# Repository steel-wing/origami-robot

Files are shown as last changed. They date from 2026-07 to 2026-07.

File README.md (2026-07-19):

# Origami Robot

This is the code behind the paper "Thickness-Invariant Origami Robots for Untethered Locomotion".

There are two primary directories here: `robotics` and `simulation`. 

## robotics

cad_model

`robotics` contains everything relating to the physical robot. It has the Platformio code used to control the physical robot constructed, with the final version of the code residing in `CMR_ORIGAMI_ROBOT_GAIT.cpp`. It has all CAD files used in the construction of the robot, as well as the custom PCBs. It contains instructions for 3D printing and assembly of parts to recreate the configuration used in the paper (see the `README.md` in the folder). It also has all materials obtained during experimentation, namely, the statistical analysis of the gaits used during testing.

## simulation

maybe

`simulation` contains everything relating to the MuJoCo simulation of the robot. It has three primary files worth inspecting.

`runner.py` is used to observe individual gait profiles, and see how they perform. It is called by `gait_finder.py` to obtain distance and rotation measurements for optimization.

`gait_finder.py` contains the optimization algorithm used to identify gaits for the robot. The `budget` and `steps` variables determine how long it will take to run, and the fidelity of the results provided.

`playground.py` is a simulator for exploring robot motion manually. It uses the number keys on the keyboard to select and control individual hinges of the robot.

See the `README.md` within `simulation` for more information about how to install MuJoCo and run the code.

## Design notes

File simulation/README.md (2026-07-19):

# Installation

1. Install [Python 3.12](https://www.python.org/ftp/python/3.12.0/)
    and make sure to add it to PATH. Then restart your IDE
2. Run these in the project folder to create a new virtual environment:

    `py -3.12 -m venv mujoco312`

    `mujoco312\Scripts\activate`

    If Powershell gives you trouble, you can run this:
    \
        `(Set-ExecutionPolicy -Scope CurrentUser -ExecutionPolicy RemoteSigned)`
3. Install the dependencies via the `requirements.txt`

    `pip install -r requirements.txt`

    (this installs the `nevergrad`, `mujoco`, and `keyboard` libraries, along with their dependencies at time of writing)

4. Run `runner.py` to play around with the model or use `gait_finder.py` to explore optimizations.

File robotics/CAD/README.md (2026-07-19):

# Overview

There are 12 cells in this robot, six male (containing motors) and six female (containing other components).
These cells are numbered following this figure:



Each cell has hinges that must be glued into place for assembly, and all six female cells have gear inserts required for motion. Hinges and hinge types vary based on location, type of cell, and whether or not the hinge borders a short edge (two of which exist on each cell) or a long edge (one of which exists on each cell). The two short edges are next to each other on one side of the cell, while the long edge sits opposite them. All hinges can reasonably be installed using cyanoacrylate glue.

## Female Cells

There are three variants of female cells in this robot: the standard female cell (`Female Cell.stl`), which is used for cells 3, 6, 8, and 12, the control module female cell (`Female Cell - Microcontroller.stl`), designed to house the microcontroller and power switch, which is used for Cell 2, and the power module female cell (`Female Cell Battery.stl`), which was designed to house batteries and buck converters, and which is used as the connection point for external power. It is used for Cell 9.

Each of the female cells uses `Female Hinge 1.stl`'s to connect to male cells bordering the short edge, and `Female Hinge 2.stl`'s to connect to male cells bordering the long edge.

In between all hinges, the female cells have an L-shaped slot that accepts a gear arm. These gear arms are used to actuate the hinge while the servo rotates.

### Electrical Components

Female Cell 2 houses the microcontroller (an ESP32 Firebeetle 2), a switch, and a battery (a 4-cell, NM 4.8V 200mAh battery).
Female Cell 9 houses batteries, buck converters, and a MOSFET for limiting power. Using electrical tape to hold different components in position is advised.
All other female cells contain PCBs for daisy-chaining power and signal data through the robot. 8-wire JST cables are used for signal transmission, and XT30 cables are used for power transmission.  

### Gear Arms

Like the gears, there are three variants of gear arms. Eight `Gear Arm Standard.stl`'s should be printed, with four being reflections of the other four. These are to be inserted in female hinges bordering short edge hinges. Four `Gear Arm Center.stl`'s should be printed and inserted in female hinges bordering long edge hinges. A final, single `Gear Arm S3170G.stl` should be inserted into the Cell 9, which is a `Female Cell Battery.stl`.

## Male Cells

There are two variants of male cells in this robot: the standard male cell (`Male Cell.stl`), which is used for cells 1, 5, 7, 10, and 11, and the modified male cell (`Male Cell - Modified (S1370G).stl`) designed to fit the Futaba SG3107 servo motor, which is used for Cell 4.

Each of the standard male cells uses one `Male Hinge 1.stl` and one `Male Hinge 2.stl` to connect to a female hinge along the short edge, and two `Male Hinge 2.stl`'s to connect to a female cell along the short edge. These hinges differ only slightly to accommodate the different geometry on different sides of the cell.

The modified male cell (Cell 4) uses modified versions of the male hinges to accommodate its altered geometry. It uses two `Male Hinge 1.stl`'s to connect to Cell 9, and two `Male Hinge 3.stl`'s and two Male Hinge 4's to connect to cells 2 and 6 (one hinge of each type connects to each of the neighboring cells.)

### Servos

Once hinges are installed, motors can be inserted. All motors are Miuzei MG90S's save for the one Futaba S3170G in Cell 4. Follow the numbered figure above for placements. The motors are all secured by a press fit, and all servo motor heads should be as close to their respective hinges as possible (as in, do not insert the servos backwards. Otherwise, the gears will be unable to mesh). Gears should not be attached to servos at this point.

## Pattern Assembly

Once all cells have had hinges glued, electrical components inserted, and the female hinges have gear arms placed, the cells can be arranged following the attached diagram. All hinges are designed to work with 3mm metal pins, which are press fit into each of the from the side. After hinges are functional, signal and power cables can be routed through cells from one component to the next. Signal wires originate at the microcontroller, with specific pins for each motor defined inside of CMR_ORIGAMI_ROBOT.cpp (line 23).

### Servo Calibration Run

Once all electronics are assembled, the buck converters should be powered with a voltage of 7.4 volts, which they will step down to the 6.0V required by the servo motors. Then the microcontroller should be powered on by its 4.8V battery, and allowed to run all motors through one run of a gait. The included `CMR_ORIGAMI_ROBOT_GAIT.cpp` will correctly position all servos at the end of the run, meaning that, so long as no hinges are actuated during assembly, gears may now be applie to the motors.

### Gear Insertion

There are three gear variants used in this model, to match the three gear arm variants. Therefore, eight `Short Edge Gear.stl`'s will be used on all short edge hinges, four `Long Edge Gear.stl`'s will be used on the four long edges, and one `S1370G Gear.stl` will be used on the centermost hinge, between Cell 4 (`Male Cell - Modified (S1370G).stl`) and Cell 9 (`Female Cell Battery.stl`).

To correctly insert all gears, it can be helpful to have a thin metal shim or spatula, and a thin pair of tweezers. It is also helpful to use a few rubber bands to hold the entire robot assembly in the closed position. Using the shim to apply a force through the gear towards the servo, slide each gear over the head of its respective servo motor, and once it gets close, press hard to ensure it slides into position. Further care should be taken to ensure that the teeth of the gear mesh with the teeth of the adjacent gear arm.

Once all gears are in position any rubber bands can be removed and the robot is ready for motion.

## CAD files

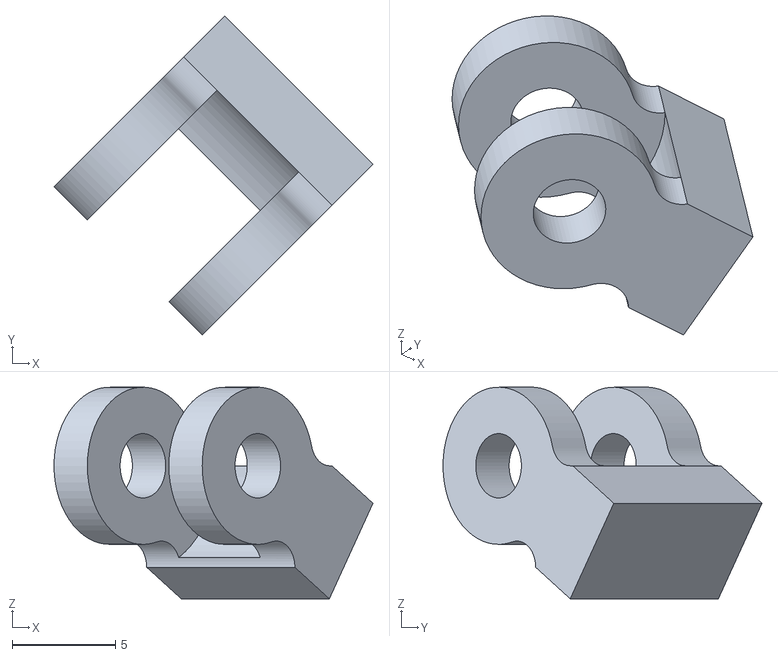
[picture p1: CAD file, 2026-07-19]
robotics/CAD/Female Cells/Female Hinge 1.stl
15.5 x 15.5 x 10.3

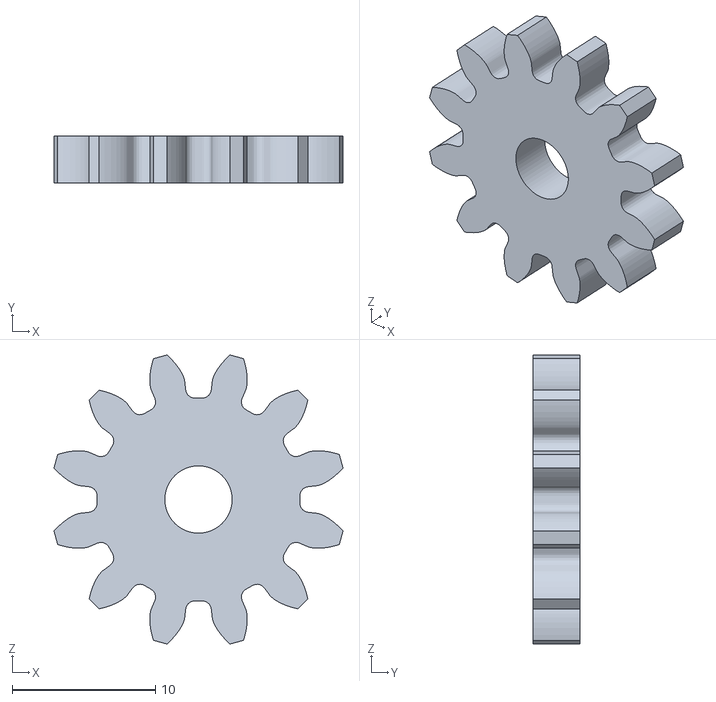
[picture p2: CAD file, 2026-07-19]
robotics/CAD/Male Cells/Long Edge Gear.stl
20.2 x 3.30 x 20.2

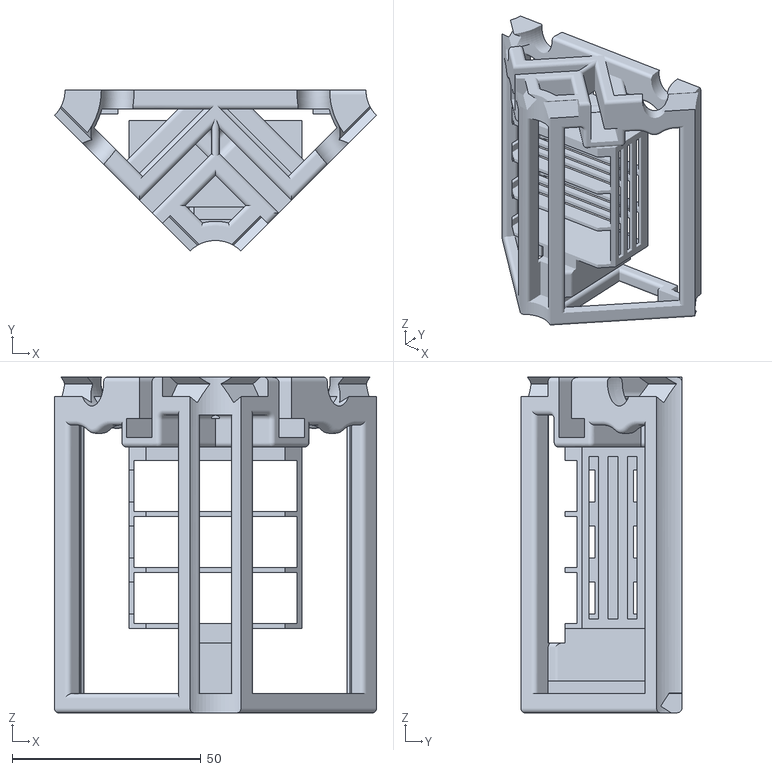
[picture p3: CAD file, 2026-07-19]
robotics/CAD/Female Cells/Female Cell - Battery.stl
85.3 x 42.7 x 88.9

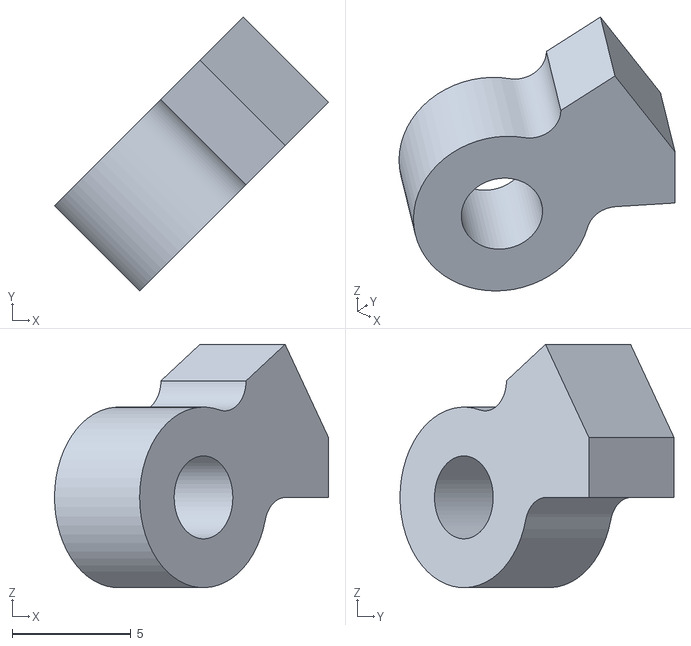
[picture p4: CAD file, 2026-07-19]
robotics/CAD/Male Cells/Male Hinge 3.stl
11.6 x 11.6 x 10.3

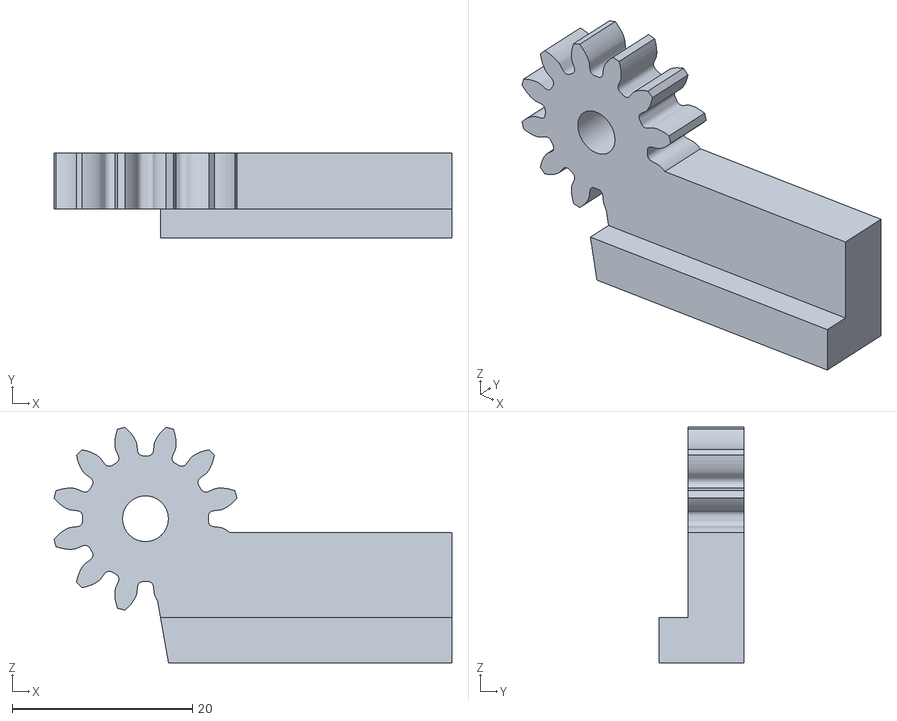
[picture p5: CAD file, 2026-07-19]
robotics/CAD/Female Cells/Long Edge Gear Arm.stl
44.2 x 9.40 x 26.2

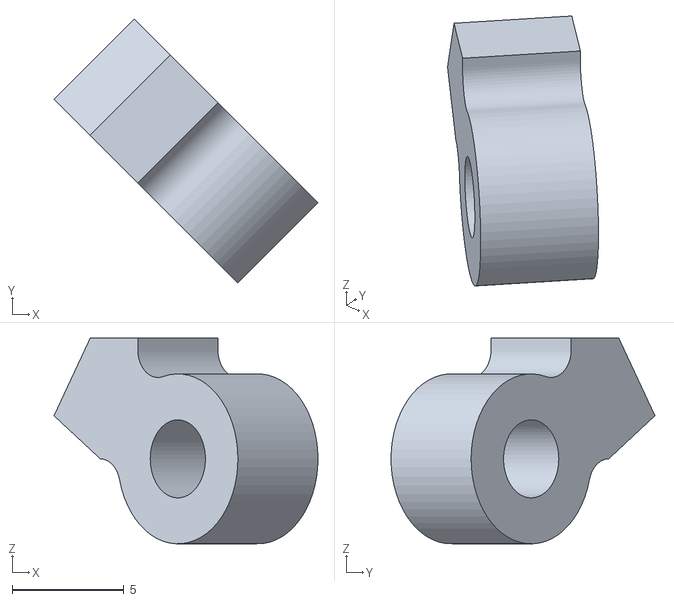
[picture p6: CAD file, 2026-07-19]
robotics/CAD/Male Cells/Male Hinge 2.stl
11.8 x 11.8 x 9.22

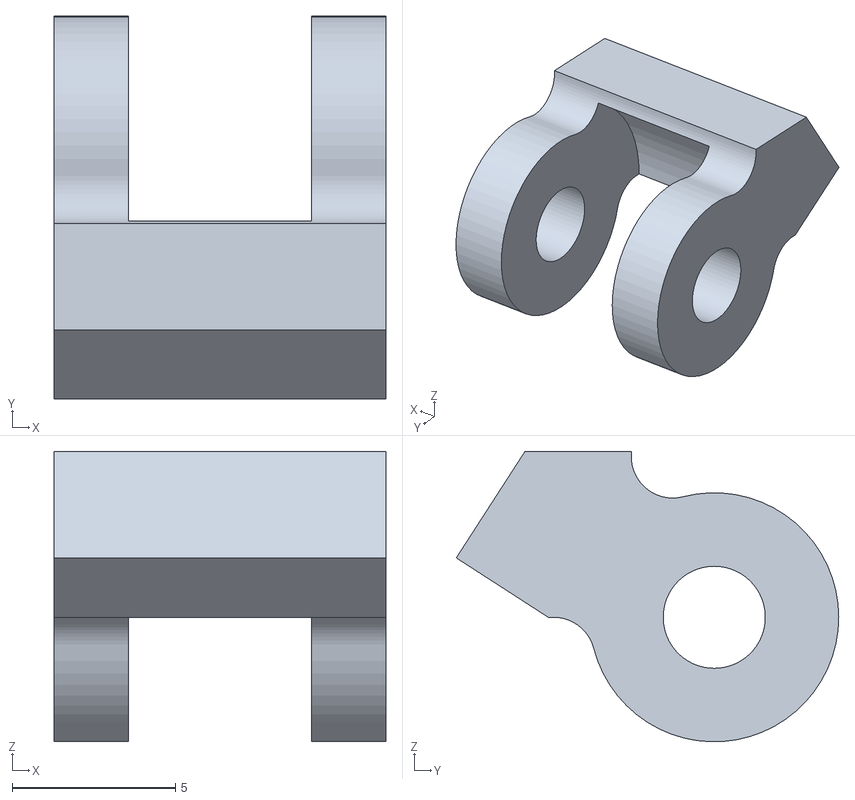
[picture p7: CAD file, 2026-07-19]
robotics/CAD/Female Cells/Female Hinge 2.stl
10.2 x 11.7 x 8.89

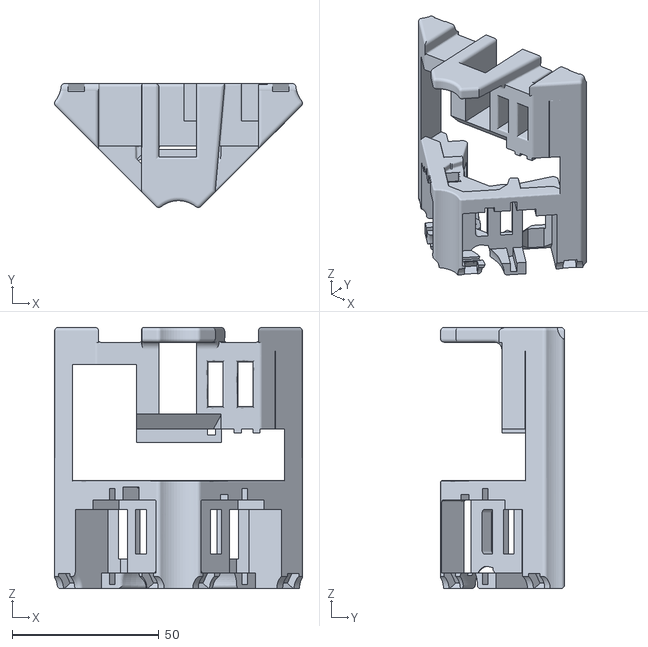
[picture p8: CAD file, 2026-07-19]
robotics/CAD/Male Cells/Male Cell.stl
84.4 x 42.2 x 88.9

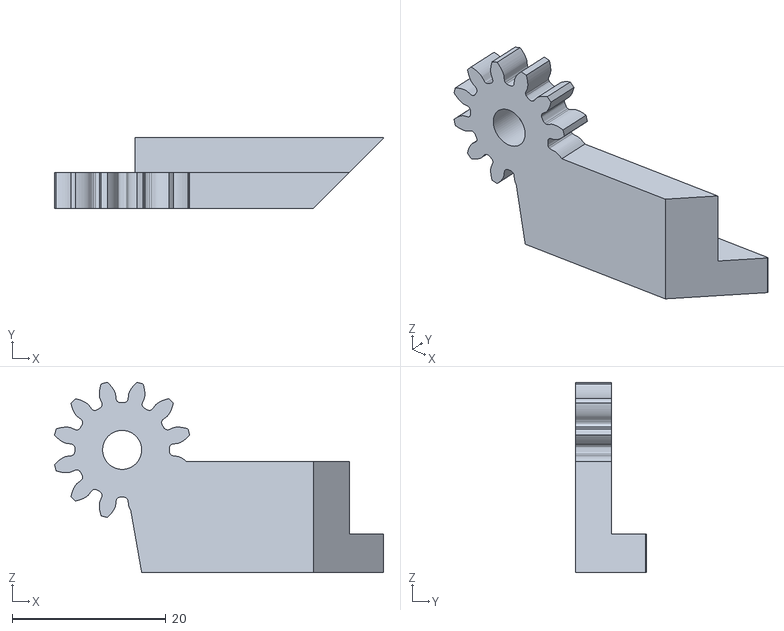
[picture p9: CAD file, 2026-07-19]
robotics/CAD/Female Cells/Short Edge Gear Arm.stl
42.9 x 9.27 x 24.8

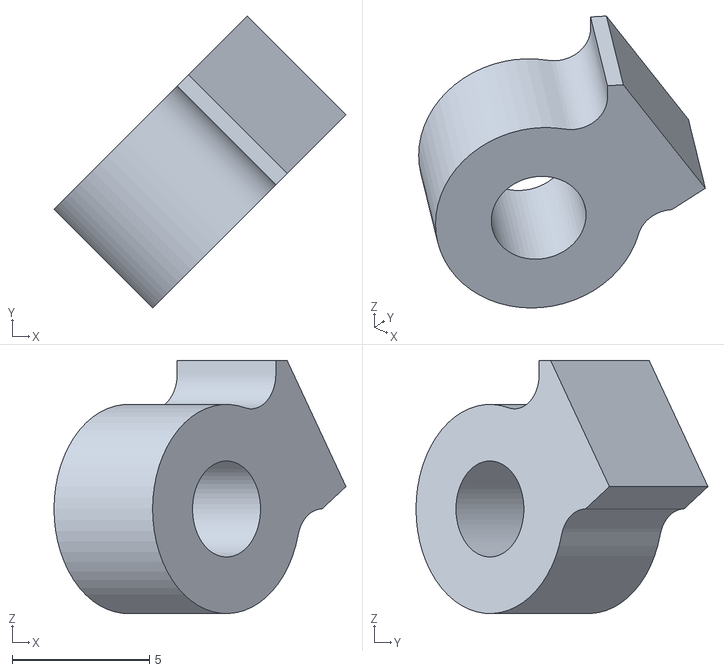
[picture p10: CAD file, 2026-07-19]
robotics/CAD/Male Cells/Male Hinge 4.stl
10.6 x 10.6 x 9.22

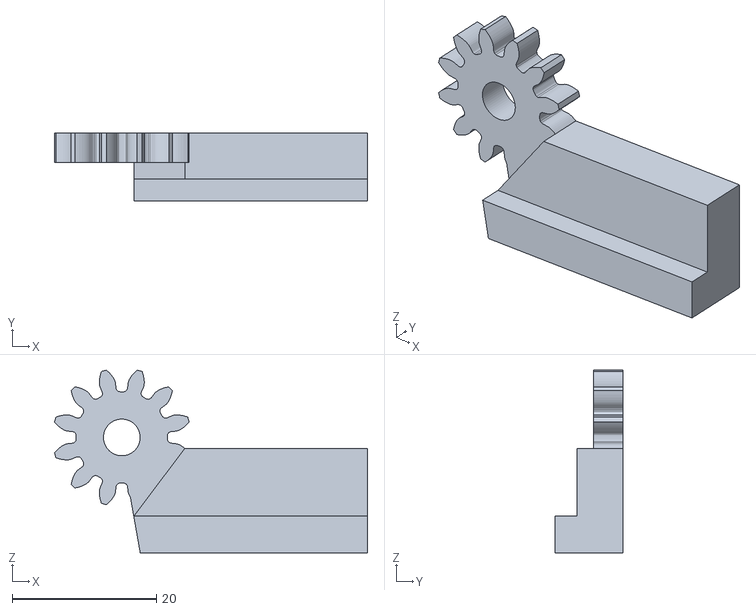
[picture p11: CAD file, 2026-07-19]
robotics/CAD/Female Cells/S3170G Gear Arm.stl
43.4 x 9.40 x 25.3

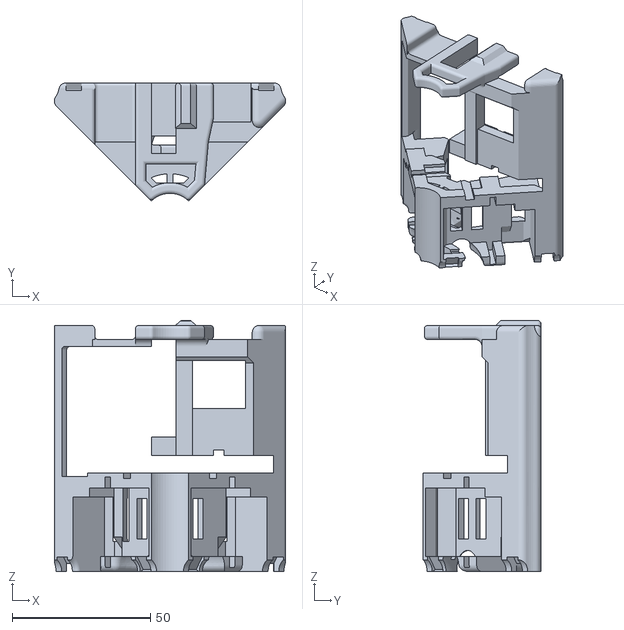
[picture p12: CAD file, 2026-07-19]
robotics/CAD/Male Cells/Male Cell - Modified (S1370G).stl
83.6 x 42.7 x 90.7

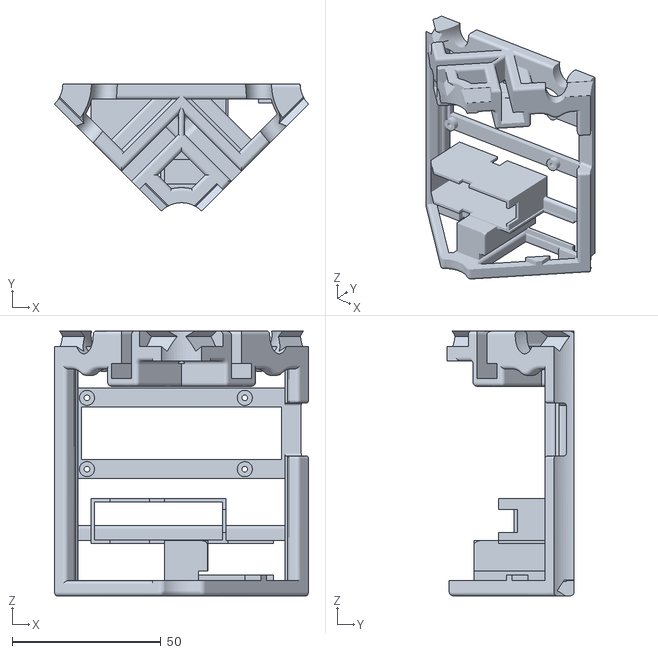
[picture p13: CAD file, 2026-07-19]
robotics/CAD/Female Cells/Female Cell - Microcontroller.stl
85.3 x 42.7 x 88.9

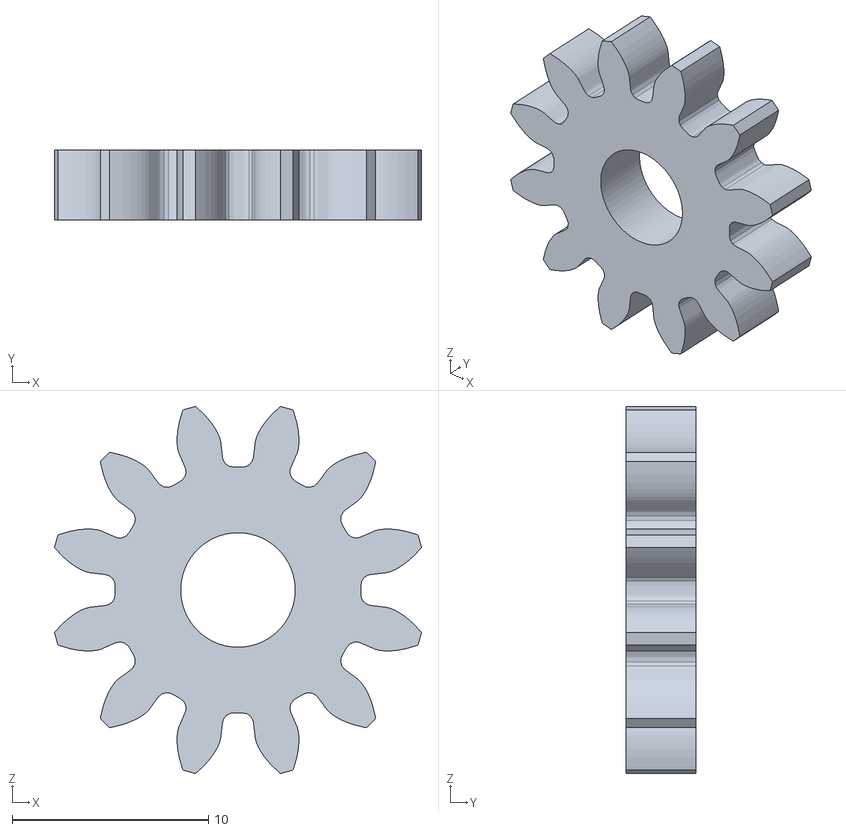
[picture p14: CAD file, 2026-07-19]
robotics/CAD/Male Cells/S1370G Gear.stl
18.7 x 3.56 x 18.7

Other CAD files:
robotics/CAD/Female Cells/Female Cell.stl
robotics/CAD/Male Cells/Male Hinge 1.stl
robotics/CAD/Male Cells/Short Edge Gear.stl

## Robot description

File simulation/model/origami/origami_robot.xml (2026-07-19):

<mujoco model="two_prisms_hinge">
    <option integrator="implicitfast" timestep="0.001"/>
    <compiler angle="radian" inertiafromgeom="true"/>
    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
    <option gravity="0 0 -9.81"/>

    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

    <worldbody>
        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
        <light pos="10 -10 20" dir="-1 1 -1.5" diffuse="0.5 0.5 0.5" directional="false" />
        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
    </worldbody>

    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
    <worldbody>
        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
        <body name="prism1_body" pos="0 0 0" euler="0 0 3.14159">
            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
            <joint type="free"/>

            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
            <body name="prism2_body" pos="0.0530 -0.0530 0" euler="0 0 3.14159">
                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
                <joint name="jaw_hinge_2" type="hinge" pos="0.02652 -0.02652 0" axis="-1 1 0" range="0 3.14" damping="0.02"/>

                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
                <body name="prism4_body" pos="0 -0.10606 0" euler="0 0 3.141592">
                    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
                    <joint name="jaw_hinge_4" type="hinge" pos="0 -0.0530 -0.09" axis="-1 0 0" range="0 3.14" damping="0.02"/>

                    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
                    <body name="prism6_body" pos="-0.0530 -0.0530 0" euler="0 0 3.141592">
                        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
                        <joint name="jaw_hinge_6" type="hinge" pos="-0.02652 -0.02652 0" axis="-1 -1 0" range="0 3.14" damping="0.02"/>
                    </body>
                </body>
            </body>

            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
            <body name="prism3_body" pos="-0.0530 -0.0530 0" euler="0 0 3.14159">
                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
                <joint name="jaw_hinge_3" type="hinge" pos="-0.02652 -0.02652 0" axis="-1 -1 0" range="0 3.14" damping="0.02"/>


                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
                <body name="prism5_body" pos="0 -0.10606 0" euler="0 0 3.141592">
                    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
                    <joint name="jaw_hinge_5" type="hinge" pos="0 -0.0530 -0.09" axis="-1 0 0" range="0 3.14" damping="0.02"/>
                </body>
            </body>

            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
            <body name="prism7_body" pos="0 -0.10606 0" euler="0 0 3.14159">
                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
                <joint name="jaw_hinge_7" type="hinge" pos="0 -0.0530 -0.09" axis="-1 0 0" range="0 3.14" damping="0.02"/>

                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
                <body name="prism8_body" pos="0.0530 -0.0530 0" euler="0 0 3.14159">
                    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
                    <joint name="jaw_hinge_8" type="hinge" pos="0.02652 -0.02652 0" axis="-1 1 0" range="0 3.14" damping="0.02"/>

                    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
                    <body name="prism10_body" pos="0 -0.10606 0" euler="0 0 3.141592">
                        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
                        <joint name="jaw_hinge_10" type="hinge" pos="0 -0.0530 -0.09" axis="-1 0 0" range="0 3.14" damping="0.02"/>

                        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
                        <body name="prism12_body" pos="-0.0530 -0.0530 0" euler="0 0 3.141592">
                            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
                            <joint name="jaw_hinge_12" type="hinge" pos="-0.02652 -0.02652 0" axis="-1 -1 0" range="0 3.14" damping="0.02"/>
                        </body>
                    </body>
                </body>

                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
                <body name="prism9_body" pos="-0.0530 -0.0530 0" euler="0 0 3.14159">
                    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
                    <joint name="jaw_hinge_9" type="hinge" pos="-0.02652 -0.02652 0" axis="-1 -1 0" range="0 3.14" damping="0.02"/>

                    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
                    <body name="prism11_body" pos="0 -0.10606 0" euler="0 0 3.141592">
                        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
                        <joint name="jaw_hinge_11" type="hinge" pos="0 -0.0530 -0.09" axis="-1 0 0" range="0 3.14" damping="0.02"/>
                    </body>
                </body>
            </body>
        </body>
    </worldbody>


    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
    <actuator>
        <position name="l_left" tendon="hinges_3_6" kp="10" kv="1" ctrlrange="0 3.14" ctrllimited="true" forcelimited="true" forcerange="-0.3924 0.3924"/>
    </actuator>

    <tendon>
        <fixed name="hinges_3_6">
            <joint joint="jaw_hinge_3" coef="0.5"/>
            <joint joint="jaw_hinge_6" coef="0.5"/>
        </fixed>
    </tendon>

    <actuator>
        <position name="r_left" joint="jaw_hinge_2" kp="10" kv="1" ctrlrange="0 3.14" ctrllimited="true" forcelimited="true" forcerange="-0.3924 0.3924"/>
    </actuator>

    <actuator>
        <position name="m_left" tendon="hinges_4_5" kp="10" kv="1" ctrlrange="0 3.14" ctrllimited="true" forcelimited="true" forcerange="-0.3924 0.3924"/>
    </actuator>

    <tendon>
        <fixed name="hinges_4_5">
            <joint joint="jaw_hinge_4" coef="0.5"/>
            <joint joint="jaw_hinge_5" coef="0.5"/>
        </fixed>
    </tendon>

    <actuator>
        <position name="center" joint="jaw_hinge_7" kp="10" kv="1" ctrlrange="0 3.14" ctrllimited="true" forcelimited="true" forcerange="-0.83385 0.83385"/>
    </actuator>

    <actuator>
        <position name="r_right" joint="jaw_hinge_8" kp="10" kv="1" ctrlrange="0 3.14" ctrllimited="true" forcelimited="true" forcerange="-0.3924 0.3924"/>
    </actuator>

    <actuator>
        <position name="l_right" tendon="hinges_9_12" kp="10" kv="1" ctrlrange="0 3.14" ctrllimited="true" forcelimited="true" forcerange="-0.3924 0.3924"/>
    </actuator>

    <tendon>
        <fixed name="hinges_9_12">
            <joint joint="jaw_hinge_9" coef="0.5"/>
            <joint joint="jaw_hinge_12" coef="0.5"/>
        </fixed>
    </tendon>

    <actuator>
        <position name="m_right" tendon="hinges_10_11" kp="10" kv="1" ctrlrange="0 3.14" ctrllimited="true" forcelimited="true" forcerange="-0.3924 0.3924"/>
    </actuator>

    <tendon>
        <fixed name="hinges_10_11">
            <joint joint="jaw_hinge_10" coef="0.5"/>
            <joint joint="jaw_hinge_11" coef="0.5"/>
        </fixed>
    </tendon>

    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
    <equality>
        <connect name="close_hex_1" body1="prism5_body" body2="prism6_body" anchor="0 0 0"/>
    </equality>

    <equality>
        <connect name="close_hex_2" body1="prism5_body" body2="prism6_body" anchor="1 -1 0"/>
    </equality>

    <equality>
        <connect name="close_hex_3" body1="prism11_body" body2="prism12_body" anchor="0 0 0"/>
    </equality>

    <equality>
        <connect name="close_hex_4" body1="prism11_body" body2="prism12_body" anchor="1 -1 0"/>
    </equality>
</mujoco>

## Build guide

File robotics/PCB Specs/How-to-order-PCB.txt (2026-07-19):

How to Order PCB

Please refer to:
https://docs.easyeda.com/en/PCB/Order-PCB

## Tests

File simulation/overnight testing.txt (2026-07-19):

        Testing mode (4, 4), with orientation 1, with y displacement loss
x 0.97
y -1.53
r 0.41
-1.53, 0.01, 0.0, 0.01, 0.0, 0.25, 2.07, 1.85, 0.16, 2.99, 1.44, 3.0, 0.2, 4, 4, 1, 1

        Testing mode (4, 4), with orientation 0, with y displacement loss
x 0.31
y 0.12
r -0.01
0.12, 1.5, 3.0, 0.34, 0.02, 0.01, 0.02, 0.01, 0.45, 1.97, 1.82, 0.04, 2.99, 4, 4, 0, 1

        Testing mode (4, 4), with orientation 1, with x displacement loss
x -1.11
y 1.59
r 0.23
-1.11, 1.38, 0.28, 0.0, 1.59, 0.26, 0.0, 2.91, 0.02, 1.87, 0.78, 3.0, 1.68, 4, 4, 1, 0

        Testing mode (4, 4), with orientation 0, with x displacement loss
x 0.13
y 0.86
r -0.31
0.13, 0.0, 0.57, 2.06, 2.37, 1.35, 0.23, 1.34, 0.0, 0.0, 1.18, 3.0, 1.09, 4, 4, 0, 0

        Testing mode (4, 4), with orientation 1, with rotation loss
x -0.13
y 1.23
r -0.04
-0.04, 0.0, 0.75, 2.4, 0.0, 3.0, 2.23, 1.85, 1.65, 0.01, 2.11, 0.2, 0.0, 4, 4, 1, 2

        Testing mode (4, 4), with orientation 0, with rotation loss
x -0.01
y -0.62
r 0.01
0.01, 0.78, 3.0, 1.7, 1.3, 0.22, 0.0, 1.74, 0.35, 0.0, 2.93, 0.01, 1.83, 4, 4, 0, 2

        Testing mode (4, 3), with orientation 1, with y displacement loss
x -0.08
y 0.31
r -0.08
0.31, 0.0, 1.08, 1.72, 1.58, 2.99, 0.86, 1.8, 0.75, 0.0, 2.18, 0.56, 2.77, 4, 3, 1, 1

        Testing mode (4, 3), with orientation 0, with y displacement loss
x 0.08
y 0.27
r -0.03
0.27, 0.0, 0.0, 0.02, 2.98, 0.0, 0.02, 0.36, 1.5, 2.94, 0.0, 0.33, 0.05, 4, 3, 0, 1

        Testing mode (4, 3), with orientation 1, with x displacement loss
x 0.26
y -0.46
r 0.74
0.26, 0.01, 0.33, 1.63, 1.86, 0.0, 2.94, 1.62, 3.0, 0.67, 0.0, 0.18, 1.32, 4, 3, 1, 0

        Testing mode (4, 3), with orientation 0, with x displacement loss
x -0.22
y -0.43
r -0.68
-0.22, 0.77, 3.0, 1.89, 0.0, 0.02, 1.03, 0.03, 0.01, 2.98, 2.99, 2.27, 0.0, 4, 3, 0, 0

        Testing mode (4, 3), with orientation 1, with rotation loss
x 0.07
y 0.72
r -0.19
-0.19, 2.94, 0.05, 1.86, 0.62, 3.0, 1.61, 1.96, 2.12, 0.27, 1.54, 0.23, 0.0, 4, 3, 1, 2

        Testing mode (4, 3), with orientation 0, with rotation loss
x 0.34
y 0.22
r -0.72
-0.72, 2.97, 0.02, 0.02, 0.02, 2.27, 2.96, 1.87, 2.99, 0.81, 1.12, 0.01, 0.0, 4, 3, 0, 2

        Testing mode (4, 1), with orientation 1, with y displacement loss
x -0.39
y -0.07
r 2.23
-0.07, 0.06, 2.71, 2.65, 2.1, 2.98, 0.69, 1.31, 0.0, 0.0, 2.99, 0.0, 0.87, 4, 1, 1, 1

        Testing mode (4, 1), with orientation 0, with y displacement loss
x -0.18
y 0.2
r 0.71
0.2, 2.09, 0.16, 2.99, 0.02, 0.96, 1.36, 0.01, 0.32, 0.0, 1.3, 2.21, 0.09, 4, 1, 0, 1

        Testing mode (4, 1), with orientation 1, with x displacement loss
x -0.31
y -0.37
r 0.18
-0.31, 0.0, 0.01, 1.15, 0.01, 0.42, 1.86, 2.19, 1.02, 0.0, 1.12, 2.99, 1.52, 4, 1, 1, 0

        Testing mode (4, 1), with orientation 0, with x displacement loss
x 0.13
y 0.24
r -1.91
0.13, 0.0, 0.19, 0.0, 0.0, 1.34, 1.19, 0.0, 0.0, 2.02, 1.92, 1.35, 0.4, 4, 1, 0, 0

        Testing mode (4, 1), with orientation 1, with rotation loss
x 0.07
y -0.42
r 2.03
2.03, 1.84, 0.01, 2.88, 1.74, 2.99, 0.86, 0.01, 1.28, 1.73, 0.0, 0.28, 1.61, 4, 1, 1, 2

        Testing mode (4, 1), with orientation 0, with rotation loss
x -0.02
y 0.04
r -3.01
-3.01, 3.0, 0.32, 2.17, 1.41, 1.08, 0.01, 0.03, 0.42, 0.0, 0.08, 1.72, 2.26, 4, 1, 0, 2

        Testing mode (3, 3), with orientation 1, with y displacement loss
x -0.0
y 0.28
r 0.0
0.28, 0.04, 0.0, 0.0, 2.98, 0.0, 0.01, 3.0, 1.15, 2.24, 0.23, 2.99, 1.48, 3, 3, 1, 1

        Testing mode (3, 3), with orientation 0, with y displacement loss
x -0.01
y -0.28
r 0.45
-0.28, 0.0, 0.65, 1.73, 0.0, 0.35, 1.67, 1.79, 0.02, 2.97, 1.74, 3.0, 0.76, 3, 3, 0, 1

        Testing mode (3, 3), with orientation 1, with x displacement loss
x 0.0
y 0.15
r -0.01
0.0, 0.34, 2.99, 1.56, 0.0, 0.0, 0.01, 2.02, 0.38, 0.02, 2.99, 0.09, 1.78, 3, 3, 1, 0

        Testing mode (3, 3), with orientation 0, with x displacement loss
x -0.05
y 0.04
r 0.68
-0.05, 0.72, 2.99, 1.73, 1.22, 0.17, 0.0, 1.93, 0.47, 0.0, 2.95, 0.01, 1.79, 3, 3, 0, 0

        Testing mode (3, 3), with orientation 1, with rotation loss
x 0.0
y -0.06
r 0.06
0.06, 0.53, 1.5, 2.16, 0.0, 0.01, 1.42, 1.35, 3.0, 1.06, 1.72, 0.07, 0.0, 3, 3, 1, 2

        Testing mode (3, 3), with orientation 0, with rotation loss
x -0.01
y 0.08
r 0.58
0.58, 1.43, 3.0, 0.26, 0.01, 0.0, 0.33, 0.01, 0.4, 2.04, 1.82, 0.06, 2.93, 3, 3, 0, 2

        Testing mode (3, 1), with orientation 1, with y displacement loss
x -0.6
y -0.66
r 0.24
-0.66, 1.81, 0.03, 2.96, 1.71, 2.99, 0.76, 0.0, 0.38, 1.53, 0.0, 0.28, 1.55, 3, 1, 1, 1

        Testing mode (3, 1), with orientation 0, with y displacement loss
x 0.27
y 0.17
r -0.21
0.17, 1.11, 0.02, 0.0, 1.65, 0.21, 0.0, 0.0, 1.19, 2.28, 1.6, 2.99, 1.14, 3, 1, 0, 1

        Testing mode (3, 1), with orientation 1, with x displacement loss
x -0.37
y -0.48
r -0.14
-0.37, 0.74, 2.99, 2.09, 0.0, 0.0, 1.17, 1.12, 0.01, 2.98, 1.87, 2.52, 0.07, 3, 1, 1, 0

        Testing mode (3, 1), with orientation 0, with x displacement loss
x 0.36
y 0.35
r -0.45
0.36, 1.98, 2.96, 0.61, 1.26, 0.0, 0.0, 2.98, 0.02, 1.34, 0.02, 2.37, 2.14, 3, 1, 0, 0

        Testing mode (3, 1), with orientation 1, with rotation loss
x -0.03
y -0.15
r -0.22
-0.22, 2.79, 0.42, 2.22, 1.68, 1.21, 0.02, 0.0, 0.42, 0.0, 0.01, 1.35, 2.19, 3, 1, 1, 2

        Testing mode (3, 1), with orientation 0, with rotation loss
x 0.28
y -0.43
r 0.85
0.85, 2.99, 0.01, 1.35, 1.21, 0.06, 3.0, 2.85, 2.41, 0.05, 2.84, 2.98, 1.54, 3, 1, 0, 2

        Testing mode (1, 1), with orientation 1, with y displacement loss
x 0.18
y -0.14
r -1.45
-0.14, 1.68, 0.48, 0.01, 1.6, 0.36, 0.0, 0.66, 3.0, 1.4, 2.97, 0.18, 2.04, 1, 1, 1, 1

        Testing mode (1, 1), with orientation 0, with y displacement loss
x -0.01
y 0.16
r -1.25
0.16, 1.63, 2.99, 1.0, 0.99, 0.02, 0.0, 3.0, 0.02, 0.0, 0.01, 1.67, 2.29, 1, 1, 0, 1

        Testing mode (1, 1), with orientation 1, with x displacement loss
x 0.06
y -0.1
r 3.36
0.06, 1.65, 0.33, 0.0, 2.98, 0.03, 1.8, 0.73, 3.0, 1.74, 1.64, 0.61, 0.01, 1, 1, 1, 0

        Testing mode (1, 1), with orientation 0, with x displacement loss
x 0.42
y -0.31
r 2.21
0.42, 0.35, 2.99, 1.68, 2.18, 2.99, 0.0, 1.75, 0.26, 0.0, 3.0, 0.1, 1.88, 1, 1, 0, 0

        Testing mode (1, 1), with orientation 1, with rotation loss
x 0.05
y -0.11
r 4.55
4.55, 0.02, 0.43, 1.84, 1.77, 0.02, 2.98, 1.65, 3.0, 0.27, 0.0, 0.0, 0.0, 1, 1, 1, 2

        Testing mode (1, 1), with orientation 0, with rotation loss
x -0.28
y -0.15
r 2.92
2.92, 0.0, 0.43, 1.83, 1.78, 0.02, 2.98, 1.83, 3.0, 0.92, 0.0, 0.44, 1.46, 1, 1, 0, 2

        Testing mode (1, 2), with orientation 1, with y displacement loss
x -0.11
y 0.11
r 1.5
0.11, 0.78, 3.0, 1.74, 1.47, 0.43, 0.0, 1.73, 0.39, 0.01, 2.99, 0.01, 1.83, 1, 2, 1, 1

        Testing mode (1, 2), with orientation 0, with y displacement loss
x 0.06
y -0.08
r 3.02
-0.08, 2.95, 0.3, 2.11, 1.37, 1.08, 0.01, 0.0, 0.38, 0.0, 0.01, 1.35, 2.13, 1, 2, 0, 1

        Testing mode (1, 2), with orientation 1, with x displacement loss
x 0.3
y -0.28
r 0.79
0.3, 1.79, 0.03, 2.98, 1.5, 2.99, 0.29, 0.0, 0.0, 0.0, 0.03, 0.44, 1.92, 1, 2, 1, 0

        Testing mode (1, 2), with orientation 0, with x displacement loss
x -0.38
y -0.11
r -2.99
-0.38, 0.0, 1.16, 1.66, 1.79, 3.0, 0.74, 1.73, 0.73, 0.0, 2.73, 0.42, 2.06, 1, 2, 0, 0

        Testing mode (1, 2), with orientation 1, with rotation loss
x 0.13
y -0.1
r -0.45
-0.45, 0.0, 0.03, 2.98, 2.35, 0.98, 0.0, 1.85, 2.97, 0.02, 0.0, 0.0, 0.08, 1, 2, 1, 2

        Testing mode (1, 2), with orientation 0, with rotation loss
x -0.21
y -0.01
r 2.17
2.17, 1.83, 0.0, 2.97, 1.74, 2.99, 0.79, 0.0, 0.36, 1.52, 0.0, 0.34, 1.58, 1, 2, 0, 2

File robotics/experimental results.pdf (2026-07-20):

distance | angle | centimeters | px->cm
Gallop1 | 1106 | 88 | 92.7881026 | distance | | 91.06 11.91963
Gallop2 | 1012 | 55 84.90195283 | average | 89.30046 | 1.970361
Gallop3 | 966 | 50 81.04277315 | stddev | 4.53548 | 8.11
Gallop4 | 1096 | 73 91.94915049 | angle | 88.57746
Gallop5 | 1096 | 70 91.94915049 | average | 71
Gallop6 | 1100 | 94 92.28473133 | stddev | 16
Gallop7 | 1075 | 67 90.18735108
Run1 | 968.76 | 10 81.27432393 | distance | 93.63
Run2 | 853.81 | 1 71.63056951 | average | 81.99642 | 14.18791
Run3 | 981 | 10 82.30120131 | stddev | 4.883337 | 22.88
Run4 | 1014 | 3 85.06974325 | angle | 433.8667
Run5 | 985 | 3 82.63678215 | average | 4.285714
Run6 | 1016 | 3 85.23753367 | stddev | 4.070802
Run7 | 1023 | 0 85.82480014
Walk1 | 638 | 23 53.52514417 | distance | 16.43
Walk2 | 601 | 36 50.42102139 | average | 50.70866 | 67.59922
Walk3 | 639 | 34 53.60903938 | stddev | 2.257315 | 155.59
Walk4 | 607 | 38 50.92439265 | angle | 333.9163
Walk5 | 565 | 41 47.40079382 | average | 35.85714
Walk6 | 596 | 40 50.00154534 | stddev | 6.148945
Walk7 | 585 | 39 49.07869803
Turn1 | 278 | 219 23.32286846 | distance | 5.62
Turn2 | 282 | 220 23.65844931 | average | 22.4959 | 75.01767
Turn3 | 281 | 216 | 23.5745541 | stddev | 1.096461 | 323.16
Turn4 | 270 | 218 22.65170678 | angle | 50.00796
Turn5 | 250 | 214 20.97380258 | average | 215.4286
Turn6 | 254 | 216 21.30938342 | stddev | 5.02849
Turn7 | 262 | 205 | 21.9805451

Summary | Mean Distance Mean Rotation dist std | rot std | MuJoCo Simulated Distance MuJoCo Simulated Rotation dist err | rot err
Turn | 22.4959 215.4286 1.096461 | 5.02849 | 5.62 | 323.16 300.2829 33.33687
Walk | 50.70866 35.85714 2.257315 6.148945 | 16.43 | 155.59 208.6346 76.95408
Run | 81.99642 4.285714 4.883337 4.070802 | 93.63 | 22.88 12.42505 81.26873
Gallop | 89.30046 | 71 | 4.53548 | 16 | 91.06 | 8.11 1.932288 775.4624

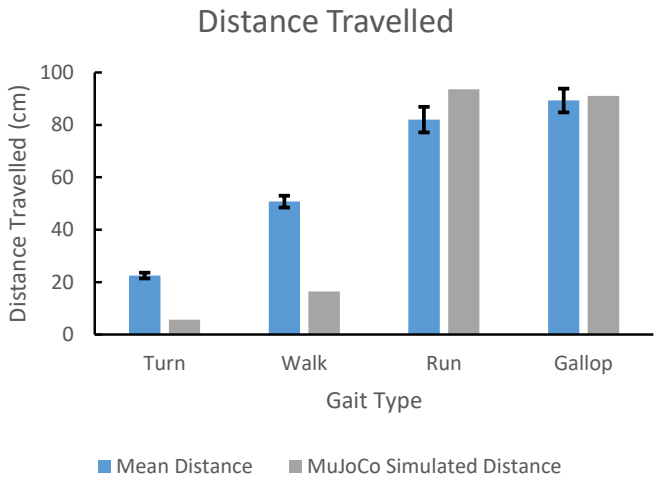
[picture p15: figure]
Turn; Walk; Run; Gallop; Distance Travelled (cm); Gait Type; Distance Travelled; Mean Distance; MuJoCo Simulated Distance
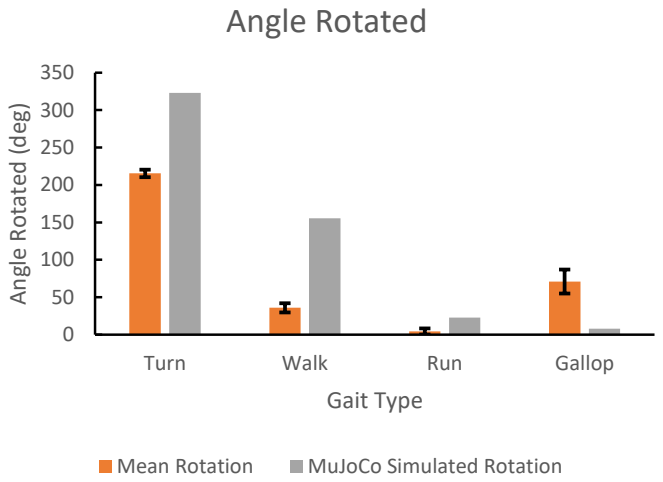
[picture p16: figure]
Turn; Walk; Run; Gallop; Angle Rotated (deg); Gait Type; Angle Rotated; Mean Rotation; MuJoCo Simulated Rotation

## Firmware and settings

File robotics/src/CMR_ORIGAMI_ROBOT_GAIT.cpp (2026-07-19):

#include <Arduino.h>
#include <ESP32Servo.h>
#include <math.h>
#include <string.h>

// constants
const float pi = 3.141592653;

// MOSFET
const int mosfetPin = 13;

// hinge variables
const int NUM_HINGES = 7;
float hingeAngles[NUM_HINGES];

// servo variables
const int NUM_SERVOS = 13;
Servo servos[NUM_SERVOS];
float servoAngles[NUM_SERVOS];

//                                 1, 2, 3, 4, 5, 6, 7, 8, 9, 10, 11, 12, 13
const int servoHinges[NUM_SERVOS] = {0, 2, 1, 3, 0, 1, 2, 5, 6, 4, 5, 4, 6};
const int servoPins[NUM_SERVOS] = {18, 23, 19, 22, 21, 2, 12, 14, 26, 25, 4, 16, 17};
const int servoType[NUM_SERVOS] = {1, 1, 2, 1, 1, 2, 1, 1, 1, 2, 1, 2, 1};

// point struct
typedef struct
{
  float x;
  float y;
  float z;
} Point3D;

// gait state struct
typedef struct
{
  Point3D p1, p2, p3, p4;
  int top;
  int bottom;
  float current_phase;
  int divisions;
  float scale;
  int current_step;
  int max_cycles;
  int ramp_steps;
  bool is_active;
} GaitState;

// gait variables
GaitState currentGait;
unsigned long lastGaitUpdate = 0;

// prototypes
Point3D eval_gait_curve(GaitState *gait, float phase);
void update_gait(GaitState *gait, float targetAngles[]);
float getTheta2(float theta1);
float getServoAngle(int i, float hingeAngles[]);
float quad_bezier(float t, float p0, float p1, float p2);

// math
float getTheta2(float theta1)
{
  return 2.0f * atanf(sqrtf(2.0f) * tanf(theta1 / 2.0f));
}

float getServoAngle(int i, float hingeAngles[])
{
  // restrict max extension due to hinge preloading
  float servoAngle = min(180.0f * hingeAngles[servoHinges[i]] / pi, 170.0f);

  // a few of the motors are installed "backwards" so we have to flip their orientation
  float angle = servoType[i] == 2 ? 180.0f - servoAngle : servoAngle;

  return angle;  
}

float quad_bezier(float t, float p0, float p1, float p2)
{
  float u = 1.0f - t;
  return (u * u * p0) + (2.0f * u * t * p1) + (t * t * p2);
}

Point3D eval_gait_curve(GaitState *gait, float phase)
{
  Point3D pts[4] = {gait->p1, gait->p2, gait->p3, gait->p4};
  Point3D mid[4];

  int max_steps = gait->max_cycles * 4 * gait->divisions;

  if (gait->current_step <= gait->ramp_steps)
  {
    gait->scale = (float)gait->current_step / (float)gait->ramp_steps;
  }
  else if (gait->current_step >= max_steps)
  {
    gait->scale = 0.0f;
    gait->is_active = false;
  }
  else if (gait->current_step >= (max_steps - gait->ramp_steps))
  {
    int steps_remaining = max(max_steps - gait->current_step, 0);
    gait->scale = (float)(steps_remaining) / (float)gait->ramp_steps;
  }
  else
  {
    gait->scale = 1.0f;
  }

  for (int i = 0; i < 4; i++)
  {
    int next = (i + 1) % 4;
    mid[i].x = (pts[i].x + pts[next].x) / 2.0f;
    mid[i].y = (pts[i].y + pts[next].y) / 2.0f;
    mid[i].z = (pts[i].z + pts[next].z) / 2.0f;
  }

  float wrapped_phase = fmodf(phase, 4.0f);
  int segment = (int)wrapped_phase;
  float local_t = wrapped_phase - segment;
  int next_mid = (segment + 1) % 4;
  int ctrl_pt = (segment + 1) % 4;

  Point3D result;
  result.x = gait->scale * quad_bezier(local_t, mid[segment].x, pts[ctrl_pt].x, mid[next_mid].x);
  result.y = gait->scale * quad_bezier(local_t, mid[segment].y, pts[ctrl_pt].y, mid[next_mid].y);
  result.z = gait->scale * quad_bezier(local_t, mid[segment].z, pts[ctrl_pt].z, mid[next_mid].z);
  return result;
}

void update_gait(GaitState *gait, float targetAngles[])
{
  if (!gait->is_active)
    return;

  Point3D targets = eval_gait_curve(gait, gait->current_phase);
  float tx = targets.x;
  float ty = targets.y;
  float tz = targets.z;

  if (gait->top == 4)
  {
    targetAngles[2] = tx;
    targetAngles[1] = getTheta2(tx);
    targetAngles[0] = getTheta2(tx);
  }
  else if (gait->top == 3)
  {
    targetAngles[2] = tx;
    targetAngles[1] = 0;
    targetAngles[0] = 0;
  }
  else if (gait->top == 2)
  {
    targetAngles[2] = 0;
    targetAngles[1] = tx;
    targetAngles[0] = 0;
  }
  else if (gait->top == 1)
  {
    targetAngles[2] = 0;
    targetAngles[1] = 0;
    targetAngles[0] = tx;
  }

  targetAngles[3] = ty;

  if (gait->bottom == 4)
  {
    targetAngles[6] = tz;
    targetAngles[4] = getTheta2(tz);
    targetAngles[5] = getTheta2(tz);
  }
  else if (gait->bottom == 3)
  {
    targetAngles[6] = tz;
    targetAngles[4] = 0;
    targetAngles[5] = 0;
  }
  else if (gait->bottom == 2)
  {
    targetAngles[6] = 0;
    targetAngles[4] = tz;
    targetAngles[5] = 0;
  }
  else if (gait->bottom == 1)
  {
    targetAngles[6] = 0;
    targetAngles[4] = 0;
    targetAngles[5] = tz;
  }

  gait->current_step++;
  gait->current_phase += 1 / (float)gait->divisions;
  if (gait->current_phase > 4)
  {
    gait->current_phase -= 4;
  }
}

void init_gait()
{
  currentGait = (GaitState){
      // .p1 = {0.56, 1.89, 0.8},        // crawl diagonal (3,1) center hinge up
      // .p2 = {2.97, 0.1, 2.93},
      // .p3 = {0.25, 0.22, 2.85},
      // .p4 = {0.25, 0.8, 0.71},
      // .top = 3,
      // .bottom = 1,
      .p1 = {0.2, 0.2, 2.2},        // gallop forwards (4,4) center hinge up
      .p2 = {2.2, 0.9, 0.2},
      .p3 = {1.8, 2.2, 0.2},
      .p4 = {0.2, 0.2, 0.2},
      .top = 4,
      .bottom = 4,
      // .p1 = {0.4, 0.4, 0.5},    // walker/rotator (1,1) center hinge down
      // .p2 = {0.3, 2.5, 2.8},
      // .p3 = {2.5, 2.5, 0.5},
      // .p4 = {1.4, 0.5, 0.5},
      // .top = 1,
      // .bottom = 1,
      // .p1 = {0.22, 0.28, 0.84},    // crab rotate plus (1,2) center hinge up
      // .p2 = {2.91, 0.15, 0.2},
      // .p3 = {1.94, 2.05, 0.2},
      // .p4 = {0.29, 2.15, 2.99},
      // .top = 1,
      // .bottom = 2,
      .current_phase = 0.0,
      .divisions = 100,
      .scale = 0.0,
      .current_step = 0,
      .max_cycles = 8,
      .ramp_steps = 400, // if you make this divisions * 4, it'll ramp up for 1 whole cycle
      .is_active = true};
}

// SETUP
void setup()
{
  Serial.begin(115200);
  delay(1000);

  pinMode(mosfetPin, OUTPUT);
  digitalWrite(mosfetPin, LOW);
  Serial.println("Power on...");

  // TURN ON MOSFET
  digitalWrite(mosfetPin, HIGH);

  // set all servos to 6 degrees
  Serial.println("Moving Servos to 6 (hold closed)");
  for (int i = 0; i < NUM_HINGES; i++)
  {
    hingeAngles[i] = 6.0 * pi/180.0;
  }

  for (int i = 0; i < NUM_SERVOS; i++)
  {
    servos[i].setPeriodHertz(50);
    // special treatment for the Futaba
    if (i == 3) {
        servos[i].attach(servoPins[i], 900, 2100);
    } else {
        servos[i].attach(servoPins[i], 500, 2500);
    }

    servoAngles[i] = getServoAngle(i, hingeAngles);
    servos[i].write(servoAngles[i]);
    Serial.print(i + 1);
    Serial.print(" ");
    Serial.print(servoHinges[i]);
    Serial.print(" ");
    Serial.print(hingeAngles[servoHinges[i]]);
    Serial.print(" ");
    Serial.println(servoAngles[i]);
  }

  // 1 second of delay
  delay(1000);

  init_gait();
  Serial.println("Initialization complete.");
}


int count = 0;

// LOOP (fixed + MOSFET OFF at end)
void loop()
{
  unsigned long now = millis();

  if (now - lastGaitUpdate >= 20)
  {
    lastGaitUpdate = now;

    if (currentGait.is_active)
    {
      update_gait(&currentGait, hingeAngles);
      count += 1;
      for (int i = 0; i < NUM_SERVOS; i++)
      {
        servoAngles[i] = getServoAngle(i, hingeAngles);
        servos[i].write(servoAngles[i]);

        // check to see that 1 and 5 aline
        if (count % 10 == 0) {
          Serial.print(i + 1);
          Serial.print(" ");
          Serial.print(servoHinges[i]);
          Serial.print(" ");
          Serial.print(hingeAngles[servoHinges[i]]);
          Serial.print(" ");
          Serial.println(servoAngles[i]);
        }
      }
      if (count % 10 == 0) {
        Serial.println(currentGait.scale);
        Serial.println("");
      }
    }
    else
    {
      delay(1000);
      Serial.println("Moving Servos to 10");
      // set all servos to 10 degrees, in case of disassembly.
      for (int i = 0; i < NUM_HINGES; i++)
      {
        hingeAngles[i] = 10.0 * pi/180.0;
      }

      for (int i = 0; i < NUM_SERVOS; i++)
      {
        servoAngles[i] = getServoAngle(i, hingeAngles);
        servos[i].write(servoAngles[i]);
        Serial.print(i + 1);
        Serial.print(" ");
        Serial.print(servoHinges[i]);
        Serial.print(" ");
        Serial.print(hingeAngles[servoHinges[i]] + 1  );
        Serial.print(" ");
        Serial.println(servoAngles[i]);
      }

      Serial.println("Powering down.");
      delay(1000);
      // TURN OFF MOSFET (same as second code)
      digitalWrite(mosfetPin, LOW);

      while (true)
      {
        Serial.println("...sleeping...");
        delay(20000);
      }
    }
  }
}
